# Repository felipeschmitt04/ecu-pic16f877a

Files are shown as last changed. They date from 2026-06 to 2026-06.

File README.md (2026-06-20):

# ECU with PIC16F877A

Academic embedded systems project developed for a **Microprocessors and
Microcontrollers** course in the Computer Engineering program at UFSC. The goal
was to build an educational ECU prototype that simulates basic combustion engine
control while integrating embedded firmware, sensor acquisition, actuator
control, an LCD interface, circuit simulation, and PCB design.

> **Disclaimer:** this project is intended for academic and portfolio purposes.
> It has not been validated for real automotive use and must not be used to
> control an actual engine without proper electrical, mechanical, and safety
> reviews.

## Overview

The ECU firmware was written in C for the **PIC16F877A** microcontroller using
MPLAB X and the XC8 compiler. The system reads simulated analog sensors, applies
fuel injection maps, controls injectors, ignition outputs, auxiliary actuators,
and displays runtime data on a 16x2 LCD.

The project includes:

- Proteus circuit simulation;
- KiCad schematic and PCB design;
- economy and performance injection maps;
- active map persistence using internal EEPROM;
- button-based user interface with LCD feedback;
- timer and interrupt-driven control logic.

## Visual Documentation

The repository includes exported hardware views that document the path from the
electrical design to the final PCB layout.

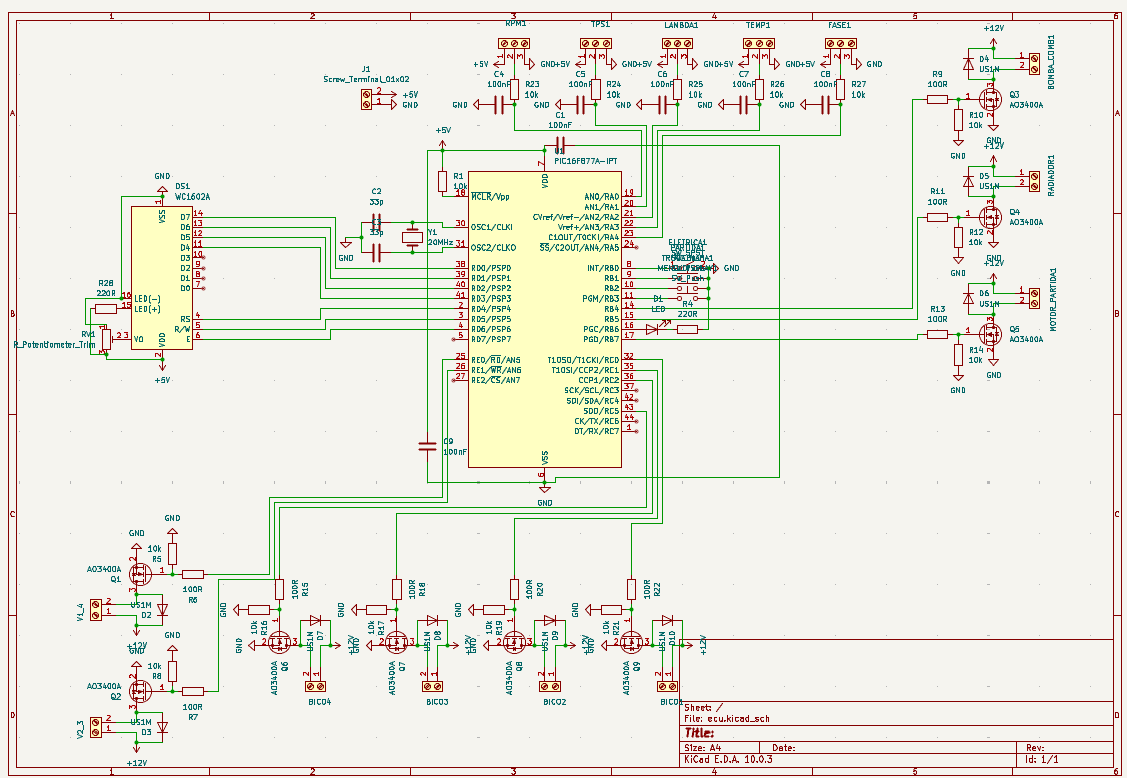
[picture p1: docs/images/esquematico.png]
KiCad schematic of the ECU circuit


The schematic centers on the PIC16F877A and shows the simulated sensor inputs,
LCD interface, user buttons, power connections, and MOSFET-based output stages
used to represent injectors, ignition pairs, the fuel pump, radiator fan,
starter motor, and warning indicators.

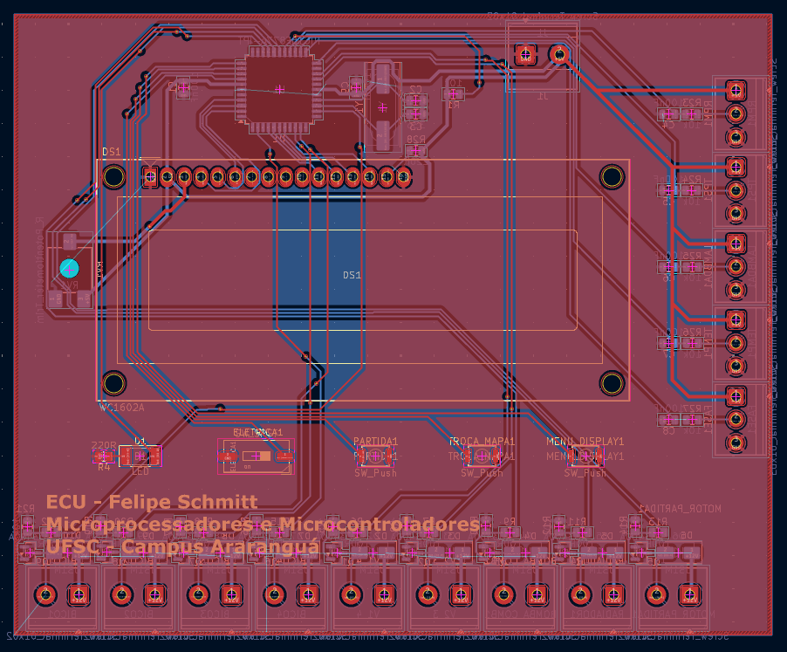
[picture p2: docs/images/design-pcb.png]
KiCad PCB routing view


The PCB layout shows the two-layer board routing, with the LCD and user controls
placed on the front side and the sensor/actuator connectors distributed around
the board edges for easier access during testing.

| Front side | Back side |
| --- | --- |
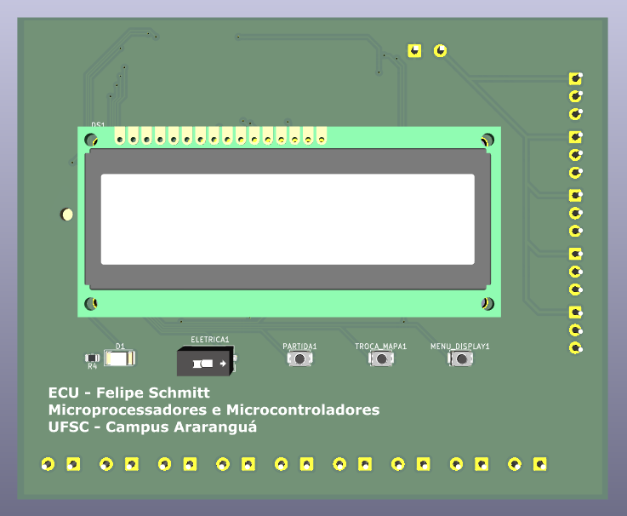
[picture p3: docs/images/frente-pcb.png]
Front render of the ECU PCB
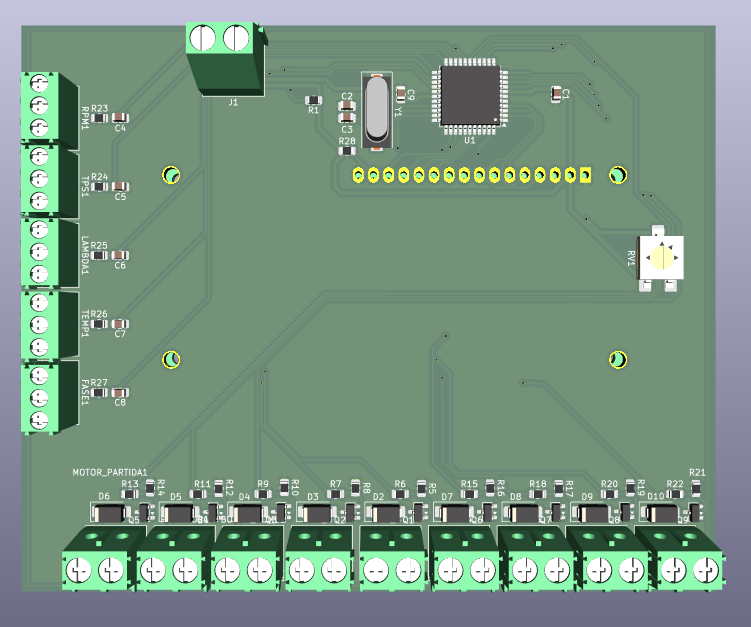
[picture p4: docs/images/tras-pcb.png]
Back render of the ECU PCB
|  |  |

The 3D renders highlight the intended physical organization of the prototype:
LCD and buttons on the user-facing side, and the microcontroller, connectors,
crystal oscillator, potentiometer, and driver stages on the opposite side.

## Features

- ADC reading for simulated sensors:
  - TPS;
  - RPM;
  - lambda/oxygen sensor;
  - temperature.
- Two injection maps:
  - economy;
  - performance.
- Sequential injector control.
- Paired ignition output control.
- Auxiliary actuator control:
  - fuel pump;
  - radiator fan;
  - starter motor;
  - check engine LED.
- Simulated open-loop and closed-loop modes.
- RPM limiter.
- Start enrichment logic.
- Multi-screen 16x2 LCD interface.

## How the ECU Works

The firmware runs a simple ECU control loop around four simulated analog
signals: throttle position, RPM, lambda/oxygen feedback, and temperature. Each
loop iteration reads the sensors through the PIC ADC, updates the engine state,
selects a fuel value from a 16x16 lookup table, applies correction rules, and
updates the auxiliary actuators and LCD.

The fuel maps use RPM and TPS as axes. The 10-bit ADC readings are compressed
to 4-bit indexes, producing 16 RPM bands and 16 throttle bands:

```c
rpm_index = adc_rpm >> 6;
tps_index = adc_tps >> 6;
map_index = rpm_index * 16 + tps_index;
```

Two maps are available: an economy map with lower base injection values and a
performance map with richer values. The selected map is stored in internal
EEPROM so the ECU can restore it after a reset.

Timer1 schedules the engine events according to the simulated RPM. On each
Timer1 interrupt, the firmware advances a four-step engine sequence, triggers
one ignition pair, and opens one injector. Timer2 then controls the injector
pulse width and turns all injectors off when the pulse ends.

For a deeper breakdown of the sensors, maps, correction logic, and actuator
states, see [ECU operation](docs/ecu-operation.md).

## Architecture

```mermaid
flowchart LR
    A["Simulated sensors<br/>TPS, RPM, lambda, temperature"] --> B["PIC16F877A ADC"]
    B --> C["ECU logic<br/>maps, corrections, limits"]
    C --> D["Timers and interrupts"]
    D --> E["Injectors"]
    D --> F["Ignition outputs"]
    C --> G["Auxiliary actuators<br/>pump, fan, starter"]
    C --> H["16x2 LCD"]
    I["Buttons"] --> C
    C --> J["Internal EEPROM<br/>active map"]
```

## Project Structure

```text
.
├── Software-MPLab/
│   └── ecu_final.X/        # C firmware for MPLAB X / XC8
├── Hardware-Proteus/       # Circuit simulation
├── PCB-Kicad/
│   └── ecu/                # Schematic and PCB files
└── docs/                   # Technical notes and portfolio assets
```

## Technologies

- **Language:** C
- **Microcontroller:** PIC16F877A
- **IDE/Compiler:** MPLAB X + XC8
- **Simulation:** Proteus
- **PCB Design:** KiCad
- **Interface:** 16x2 LCD in 4-bit mode

## How to Open

### Firmware

1. Open `Software-MPLab/ecu_final.X` in MPLAB X.
2. Confirm that the selected device is `PIC16F877A`.
3. Build the project with the XC8 compiler.

### Simulation

1. Open `Hardware-Proteus/ecu3.pdsprj` in Proteus.
2. Attach the `.hex` file generated by MPLAB to the simulated microcontroller,
   if required.
3. Run the simulation and vary the sensor inputs to observe the ECU behavior.

### PCB

1. Open `PCB-Kicad/ecu/ecu.kicad_pro` in KiCad.
2. Review the schematic and PCB layout.
3. Run ERC/DRC before considering any manufacturing step.

## Known Limitations

This project was developed as an academic prototype. Before any use beyond
simulation, the following areas would need additional work:

- validate the electrical sizing of inductive load drivers;
- replace floating-point calculations with integer or fixed-point arithmetic to
  reduce program memory usage;
- protect variables shared between `main` and interrupt routines;
- review LCD buffers and string formatting;
- make the build reproducible outside the original MPLAB/XC8 environment;
- run and document KiCad ERC/DRC results.

## Outcome

The project was presented for the Microprocessors and Microcontrollers course
and received the maximum grade. It demonstrates practical integration between
embedded firmware, analog/digital electronics, real-time control, circuit
simulation, and PCB design.

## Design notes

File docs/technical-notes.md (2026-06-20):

# Technical Notes

## Academic Goal

The goal of this project was to apply microprocessor and microcontroller
concepts in an embedded system with multiple inputs and outputs, real-time
timing requirements, and interaction with simulated hardware.

## Firmware

The firmware is centered around `Software-MPLab/ecu_final.X/main.c` and uses:

- PIC16F877A configuration bits;
- ADC for sensor acquisition;
- Timer1 as the base timing source for the engine cycle;
- Timer2 for injector pulse duration;
- interrupts for injection and ignition timing events;
- internal EEPROM to store the active map;
- a 16x2 LCD for the local interface.

## Inputs

| Input | Function |
| --- | --- |
| AN0 | Simulated TPS |
| AN1 | Simulated RPM |
| AN2 | Simulated lambda/oxygen sensor |
| AN3 | Simulated temperature |
| RB0 | Ignition switch |
| RB1 | Starter button |
| RB2 | Map switch / loop mode |
| RB3 | Display menu |

## Outputs

| Output | Function |
| --- | --- |
| RB4 | Fuel pump |
| RB5 | Radiator fan |
| RB6 | Check engine LED |
| RB7 | Starter motor |
| RC0, RC1, RC2, RC5 | Injectors |
| RE0, RE1 | Ignition pairs |
| RD0-RD4, RD6 | 16x2 LCD |

## Control Logic

RPM and TPS values select an entry from a 16x16 lookup table. The selected
value defines the base injector pulse time. The ECU also applies additional
rules for engine start, RPM limiting, deceleration fuel cut, and lambda-based
correction in simulated closed-loop mode.

A more detailed explanation of the runtime behavior is available in
[ECU operation](ecu-operation.md).

## Hardware Documentation

The `docs/images` directory contains exported views used to document the
hardware portion of the project:

- `esquematico.png`: KiCad schematic with the PIC16F877A, simulated analog
  sensors, LCD, buttons, and actuator driver stages.
- `design-pcb.png`: PCB routing view showing the two-layer board layout.
- `frente-pcb.png`: front 3D render with the LCD, user controls, and silkscreen.
- `tras-pcb.png`: back 3D render with the microcontroller, connectors, crystal,
  potentiometer, and output driver circuitry.

## Learning Outcomes

- Peripheral configuration on an 8-bit microcontroller.
- Timer and interrupt-driven event handling.
- ADC acquisition and conversion of simulated physical quantities.
- Calibration map organization.
- Integration between firmware, simulation, and PCB design.
- Practical program memory constraints in small microcontrollers.

## Future Improvements

- Split the firmware into smaller modules.
- Replace floating-point calculations with fixed-point arithmetic.
- Add abstraction layers for the LCD and actuators.
- Add logic tests for maps and limit conditions.
- Add Proteus screenshots to complement the KiCad schematic and PCB renders.
- Review ERC/DRC results and document them in the repository.

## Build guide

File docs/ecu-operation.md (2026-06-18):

# ECU Operation

This document describes how the simulated ECU firmware works at a higher level:
which sensors are read, how the fuel maps are indexed, how the engine state is
updated, and how the outputs are driven.

## Main Control Loop

The firmware starts by configuring the PIC16F877A ports, ADC, timers, LCD, and
interrupts. It then reads the last selected fuel map from internal EEPROM and
enters the main loop.

When the ignition switch is active, each loop iteration performs the following
steps:

1. Read buttons and update the user interface state.
2. Read analog sensors through the ADC.
3. Detect whether the starter button is pressed.
4. Calculate the engine logic and injector pulse value.
5. Update auxiliary actuators.
6. Refresh the LCD periodically.

When the ignition switch is off, the firmware disables the pump, fan, starter,
ignition outputs, injectors, and timers.

## Sensor Inputs

The project uses simulated sensors connected to the PIC ADC channels.

| ADC channel | Variable | Simulated signal | Firmware interpretation |
| --- | --- | --- | --- |
| AN0 | `g_adc_tps` | Throttle position sensor | Used as the TPS axis of the fuel map and for deceleration fuel cut |
| AN1 | `g_adc_rpm_sim` | RPM potentiometer/signal | Converted into simulated engine speed and used as the RPM axis |
| AN2 | `g_adc_sonda` | Lambda/oxygen sensor | Converted into an AFR-like value for closed-loop correction |
| AN3 | `g_adc_temp` | Temperature sensor | Converted into degrees Celsius for fan control and warnings |

The ADC returns a 10-bit value from 0 to 1023. The simulated RPM is calculated
as:

```c
g_rpm_real = g_adc_rpm_sim * 8;
```

This maps the ADC range to approximately 0 to 8184 RPM.

The simulated lambda input is converted into an AFR-like range from 10.0 to
20.0:

```c
afr_lido = 10.0 + (g_adc_sonda * 10.0 / 1023.0);
```

Temperature is approximated with:

```c
temperatura = g_adc_temp * 0.4887;
```

## Digital Inputs

| Pin | Symbol | Function |
| --- | --- | --- |
| RB0 | `SW_IGNICAO` | Ignition switch |
| RB1 | `SW_PARTIDA` | Starter button |
| RB2 | `SW_MAPA` | Short press changes fuel map; long press changes loop mode |
| RB3 | `SW_MENU` | Cycles LCD display screens |

The inputs use active-low logic in the firmware, so a pressed/active switch is
read as `0`.

## Engine State

The firmware tracks three main operating states:

| State variable | Meaning |
| --- | --- |
| `g_ignicao_ligada` | Ignition switch is active |
| `g_modo_partida` | Starter button is pressed |
| `g_motor_girando` | Engine is considered running |

The engine is considered running when the starter is active and the simulated
RPM is above 300 RPM. If the engine is already running and RPM drops below 400
RPM, the firmware considers the engine stopped and disables Timer1 and all
injectors.

## Fuel Maps

The project contains two 16x16 fuel maps:

- `MAPA_ECONOMICO`: lower base injection values for economy mode;
- `MAPA_PERFORMANCE`: higher base injection values for performance mode.

Both maps contain 256 entries. The axes are simulated RPM and TPS. Since each
ADC reading is 10 bits, the firmware compresses each value into a 4-bit index:

```c
rpm_index = g_adc_rpm_sim >> 6;  // 0 to 15
tps_index = g_adc_tps >> 6;      // 0 to 15
index_linear = rpm_index * 16 + tps_index;
```

The selected map entry becomes the base injector pulse value:

```c
tempo_base = MAPA_ECONOMICO[index_linear];
// or
tempo_base = MAPA_PERFORMANCE[index_linear];
```

The active map is saved in EEPROM address `0` when changed while the engine is
not running. On startup, the firmware restores the saved map; invalid values
fall back to the economy map.

## Fuel Corrections

After reading the base value from the selected map, the firmware applies several
rules.

### Closed-Loop Correction

When closed-loop mode is enabled, the simulated lambda sensor is converted into
an AFR-like value. The target AFR is fixed at 14.7. A correction factor is
computed and clamped between 0.70 and 1.30 to avoid extreme corrections.

### RPM Limiter

If simulated RPM exceeds `RPM_LIMITE` (`6500`), the firmware sets the final
injection value to zero.

### Deceleration Fuel Cut

If TPS is near zero and RPM is above 1800, the firmware also sets the final
injection value to zero to simulate fuel cut during deceleration.

### Start Enrichment

When the starter is active, the final injection value is multiplied by 1.3 to
simulate a richer mixture during start.

### Timer2 Limit

The final value is capped at 255 because it is stored in an 8-bit Timer2 period
register value.

## Timer-Based Injection and Ignition

The firmware uses two timers:

| Timer | Purpose |
| --- | --- |
| Timer1 | Schedules engine events according to simulated RPM |
| Timer2 | Ends the injector pulse |

Timer1 is reloaded with a value calculated from the simulated RPM:

```c
ticks = 18750000 / g_rpm_real;
g_timer1_preload = 65535 - ticks;
```

On each Timer1 interrupt, the firmware advances a four-step sequence:

| Step | Ignition output | Injector opened |
| --- | --- | --- |
| 0 | `VELA_1_4` | `BICO_3` |
| 1 | `VELA_2_3` | `BICO_4` |
| 2 | `VELA_1_4` | `BICO_2` |
| 3 | `VELA_2_3` | `BICO_1` |

After opening an injector, Timer2 is started with the calculated pulse value.
When Timer2 overflows, all injectors are turned off.

## Auxiliary Actuators

| Output | Pin | Behavior |
| --- | --- | --- |
| Fuel pump | RB4 | Turns on while the engine is running; also primes briefly after ignition is switched on |
| Radiator fan | RB5 | Turns on above 95 C and turns off below 90 C |
| Check engine LED | RB6 | Turns on for TPS fault, high temperature, or RPM limiter condition |
| Starter motor | RB7 | Turns on while starter mode is active and the engine is not yet running |

The system shutdown routine clears all auxiliary outputs, ignition outputs,
injectors, and timers.

## LCD Interface

The LCD has three display modes:

| Mode | Displayed information |
| --- | --- |
| General | RPM, TPS, AFR, or a sport-style RPM bar depending on the active map |
| Map | Active fuel map and loop mode |
| Warnings | Temperature and system warnings |

The menu button cycles between these modes. The map button changes the fuel map
on a short press and toggles open-loop/closed-loop mode on a long press.

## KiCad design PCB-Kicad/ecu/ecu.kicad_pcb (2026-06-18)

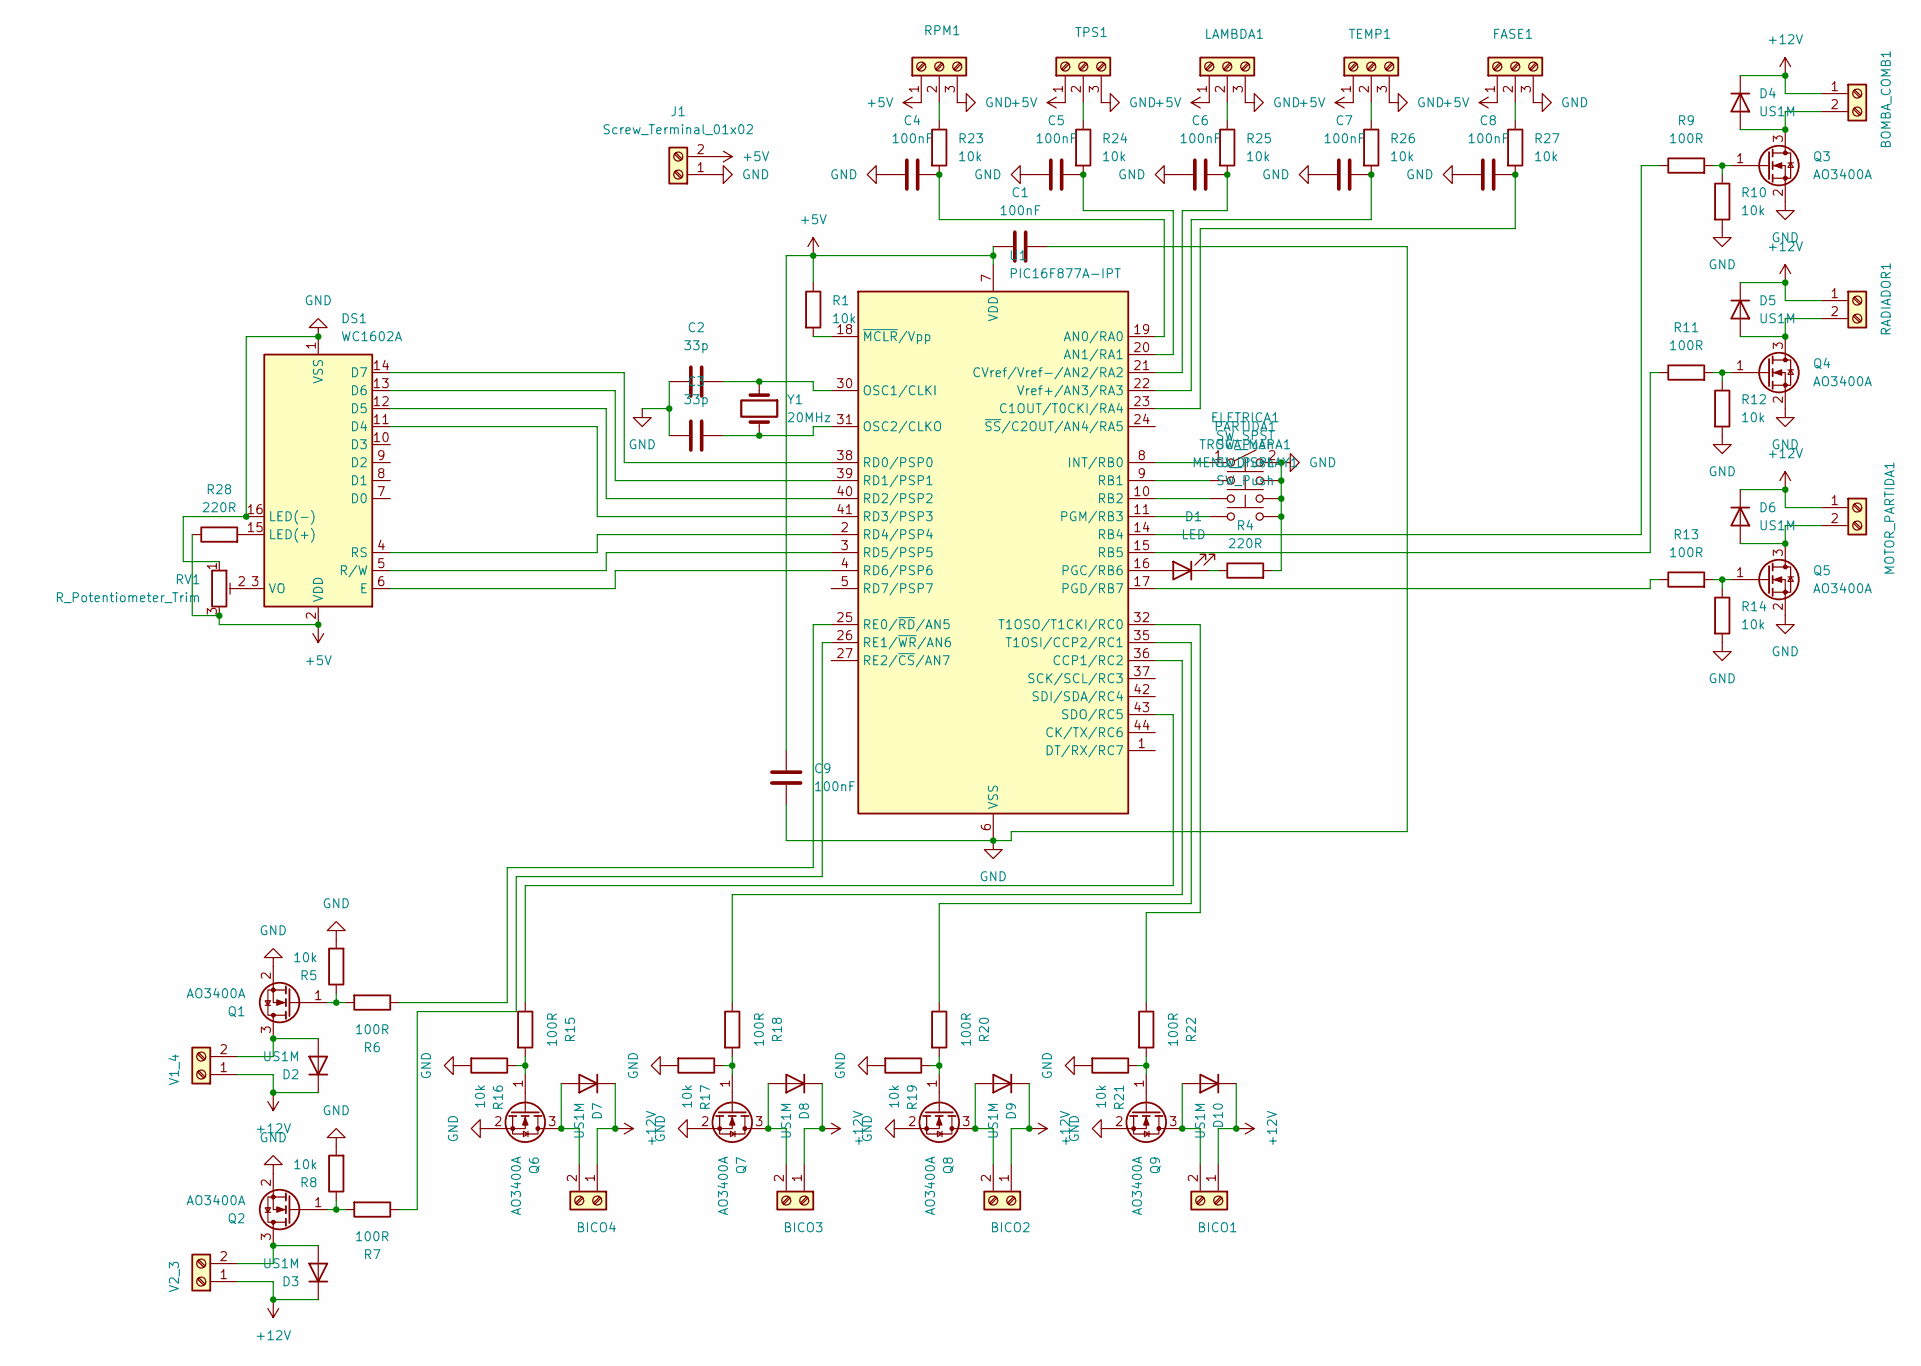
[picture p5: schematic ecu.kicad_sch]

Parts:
BICO1, BICO2, BICO3, BICO4: Screw_Terminal_01x02; TerminalBlock_Phoenix_PT-1,5-2-5.0-H_1x02_P5.00mm_Horizontal
BOMBA_COMB1: Screw_Terminal_01x02; TerminalBlock_Phoenix_PT-1,5-2-5.0-H_1x02_P5.00mm_Horizontal
C1, C4, C5, C6, C7, C8, C9: 100nF; C_0805_2012Metric
C2, C3: 33p; C_0805_2012Metric
D1: LED; LED_2010_5025Metric
D2, D3, D4, D5, D6, D7, D8, D9, D10: US1M; D_SMA
DS1: WC1602A
ELETRICA1: SW_SPST; SW_DIP_SPSTx01_Slide_9.78x4.72mm_W8.61mm_P2.54mm
FASE1: Screw_Terminal_01x03; TerminalBlock_Phoenix_PT-1,5-3-3.5-H_1x03_P3.50mm_Horizontal
J1: Screw_Terminal_01x02; TerminalBlock_Phoenix_MKDS-1,5-2-5.08_1x02_P5.08mm_Horizont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
LAMBDA1: Screw_Terminal_01x03; TerminalBlock_Phoenix_PT-1,5-3-3.5-H_1x03_P3.50mm_Horizontal
MENU_DISPLAY1: SW_Push; SW_Push_SPST_NO_Alps_SKRK
MOTOR_PARTIDA1: Screw_Terminal_01x02; TerminalBlock_Phoenix_PT-1,5-2-5.0-H_1x02_P5.00mm_Horizontal
PARTIDA1: SW_Push; SW_Push_SPST_NO_Alps_SKRK
Q1, Q2, Q3, Q4, Q5, Q6, Q7, Q8, Q9: AO3400A; SOT-23
R1, R5, R8, R10, R12, R14, R16, R17, R19, R21, R23, R24, R25, R26, R27: 10k; R_0805_2012Metric
R4, R28: 220R; R_0805_2012Metric
R6, R7, R9, R11, R13, R15, R18, R20, R22: 100R; R_0805_2012Metric
RADIADOR1: Screw_Terminal_01x02; TerminalBlock_Phoenix_PT-1,5-2-5.0-H_1x02_P5.00mm_Horizontal
RPM1: Screw_Terminal_01x03; TerminalBlock_Phoenix_PT-1,5-3-3.5-H_1x03_P3.50mm_Horizontal
RV1: R_Potentiometer_Trim; Potentiometer_ACP_CA6-VSMD_Vertical_Hole
TEMP1: Screw_Terminal_01x03; TerminalBlock_Phoenix_PT-1,5-3-3.5-H_1x03_P3.50mm_Horizontal
TPS1: Screw_Terminal_01x03; TerminalBlock_Phoenix_PT-1,5-3-3.5-H_1x03_P3.50mm_Horizontal
TROCA_MAPA1: SW_Push; SW_Push_SPST_NO_Alps_SKRK
U1: PIC16F877A-IPT; TQFP-44_10x10mm_P0.8mm
V1_4, V2_3: Screw_Terminal_01x02; TerminalBlock_Phoenix_PT-1,5-2-5.0-H_1x02_P5.00mm_Horizontal
Y1: 20MHz; Crystal_SMD_HC49-SD

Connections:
+5V: C1.1, C9.2, DS1.2 (VDD), FASE1.1, J1.2, LAMBDA1.1, R1.1, R28.1, RPM1.1, RV1.3, TEMP1.1, TPS1.1, U1.7 (VDD), U1.28 (VDD)
+12V: BICO1.1, BICO2.1, BICO3.1, BICO4.1, BOMBA_COMB1.1, D2.1 (K), D3.1 (K), D4.1 (K), D5.1 (K), D6.1 (K), D7.1 (K), D8.1 (K), D9.1 (K), D10.1 (K), MOTOR_PARTIDA1.1, RADIADOR1.1, V1_4.1, V2_3.1
GND: C1.2, C2.1, C3.1, C4.1, C5.1, C6.1, C7.1, C8.1, C9.1, DS1.1 (VSS), DS1.16 (LED(-)), ELETRICA1.2 (B), FASE1.3, J1.1, LAMBDA1.3, MENU_DISPLAY1.2, PARTIDA1.2, Q1.2 (S), Q2.2 (S), Q3.2 (S), Q4.2 (S), Q5.2 (S), Q6.2 (S), Q7.2 (S), Q8.2 (S), Q9.2 (S), R4.2, R5.2, R8.2, R10.2, R12.2, R14.2, R16.2, R17.2, R19.2, R21.2, RPM1.3, RV1.1, TEMP1.3, TPS1.3, TROCA_MAPA1.2, U1.6 (VSS), U1.29 (VSS)
unnamed: BICO1.2, D10.2 (A), Q9.3 (D)
unnamed: BICO2.2, D9.2 (A), Q8.3 (D)
unnamed: BICO3.2, D8.2 (A), Q7.3 (D)
unnamed: BICO4.2, D7.2 (A), Q6.3 (D)
unnamed: BOMBA_COMB1.2, D4.2 (A), Q3.3 (D)
unnamed: D1.2 (A), U1.16 (PGC/RB6)
unnamed: D1.1 (K), R4.1
unnamed: D2.2 (A), Q1.3 (D), V1_4.2
unnamed: D3.2 (A), Q2.3 (D), V2_3.2
unnamed: D5.2 (A), Q4.3 (D), RADIADOR1.2
unnamed: D6.2 (A), MOTOR_PARTIDA1.2, Q5.3 (D)
unnamed: DS1.11 (D4), U1.41 (RD3/PSP3)
unnamed: DS1.12 (D5), U1.40 (RD2/PSP2)
unnamed: DS1.13 (D6), U1.39 (RD1/PSP1)
unnamed: DS1.14 (D7), U1.38 (RD0/PSP0)
unnamed: DS1.6 (E), U1.4 (RD6/PSP6)
unnamed: DS1.15 (LED(+)), R28.2
unnamed: DS1.4 (RS), U1.2 (RD4/PSP4)
unnamed: DS1.5 (R/W), U1.3 (RD5/PSP5)
unnamed: DS1.3 (VO), RV1.2
unnamed: ELETRICA1.1 (A), U1.8 (INT/RB0)
unnamed: FASE1.2, R27.1
unnamed: LAMBDA1.2, R25.1
unnamed: Q1.1 (G), R5.1, R6.2
unnamed: Q2.1 (G), R7.2, R8.1
unnamed: Q3.1 (G), R9.2, R10.1
unnamed: Q4.1 (G), R11.2, R12.1
unnamed: Q5.1 (G), R13.2, R14.1
unnamed: Q6.1 (G), R15.2, R16.1
unnamed: Q7.1 (G), R17.1, R18.2
unnamed: Q8.1 (G), R19.1, R20.2
unnamed: Q9.1 (G), R21.1, R22.2
unnamed: R23.1, RPM1.2
unnamed: R26.1, TEMP1.2
unnamed: R24.1, TPS1.2
unnamed: C4.2, R23.2, U1.19 (AN0/RA0)
unnamed: C5.2, R24.2, U1.20 (AN1/RA1)
unnamed: C8.2, R27.2, U1.23 (C1OUT/T0CKI/RA4)
unnamed: R18.1, U1.36 (CCP1/RC2)
unnamed: C6.2, R25.2, U1.21 (CVref/Vref-/AN2/RA2)
unnamed: C2.2, U1.30 (OSC1/CLKI), Y1.1
unnamed: C3.2, U1.31 (OSC2/CLKO), Y1.2
unnamed: R13.1, U1.17 (PGD/RB7)
unnamed: MENU_DISPLAY1.1, U1.11 (PGM/RB3)
unnamed: PARTIDA1.1, U1.9 (RB1)
unnamed: TROCA_MAPA1.1, U1.10 (RB2)
unnamed: R9.1, U1.14 (RB4)
unnamed: R11.1, U1.15 (RB5)
unnamed: R6.1, U1.25 (RE0/~RD/AN5)
unnamed: R7.1, U1.26 (RE1/~WR/AN6)
unnamed: R15.1, U1.43 (SDO/RC5)
unnamed: R20.1, U1.35 (T1OSI/CCP2/RC1)
unnamed: R22.1, U1.32 (T1OSO/T1CKI/RC0)
unnamed: C7.2, R26.2, U1.22 (Vref+/AN3/RA3)
unnamed: R1.2, U1.18 (~MCLR/Vpp)

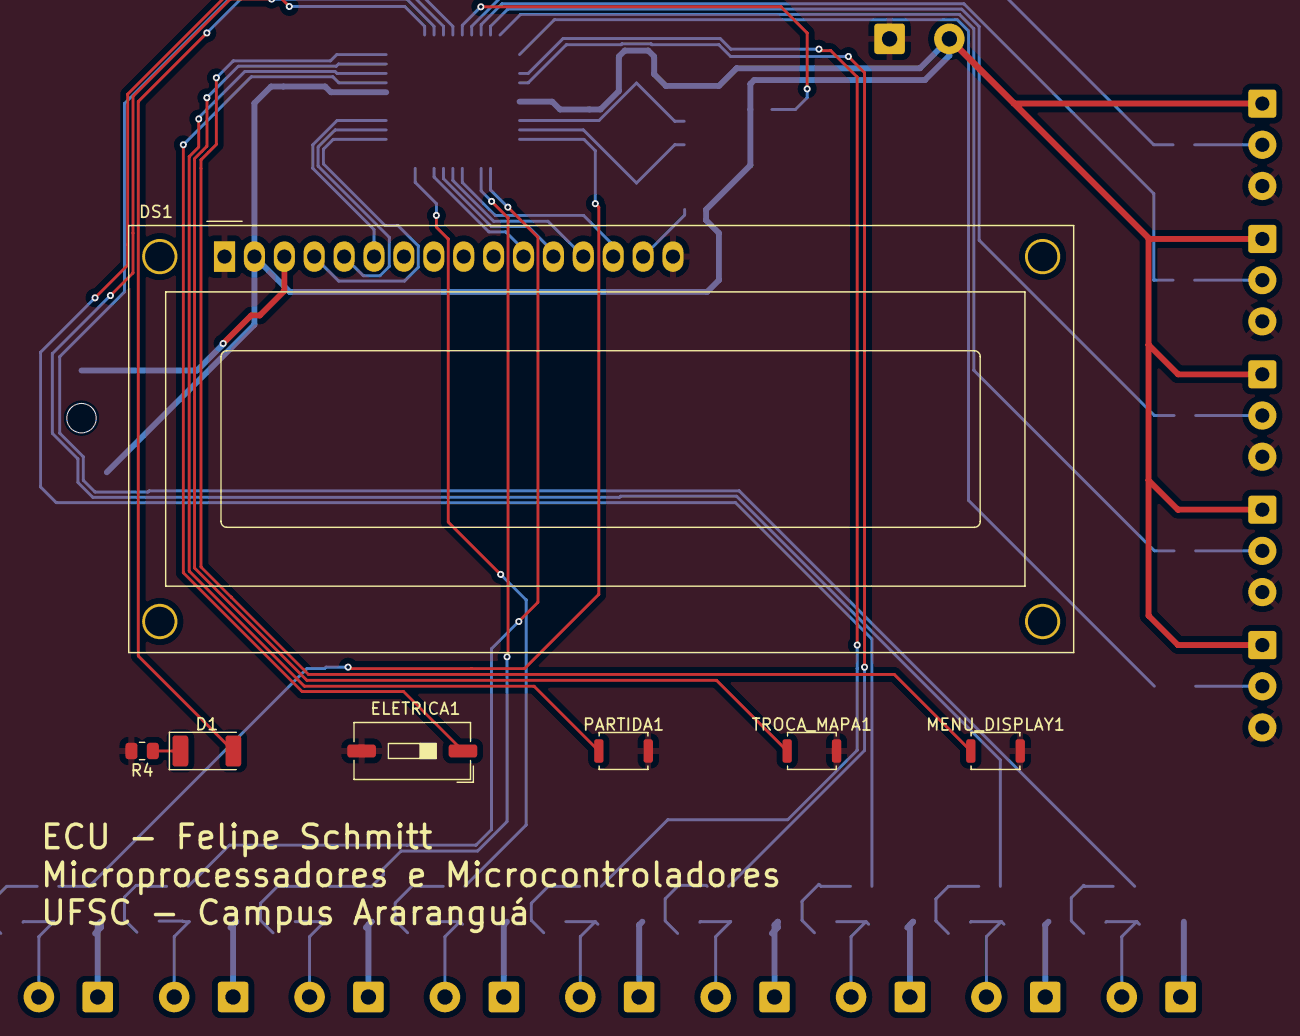
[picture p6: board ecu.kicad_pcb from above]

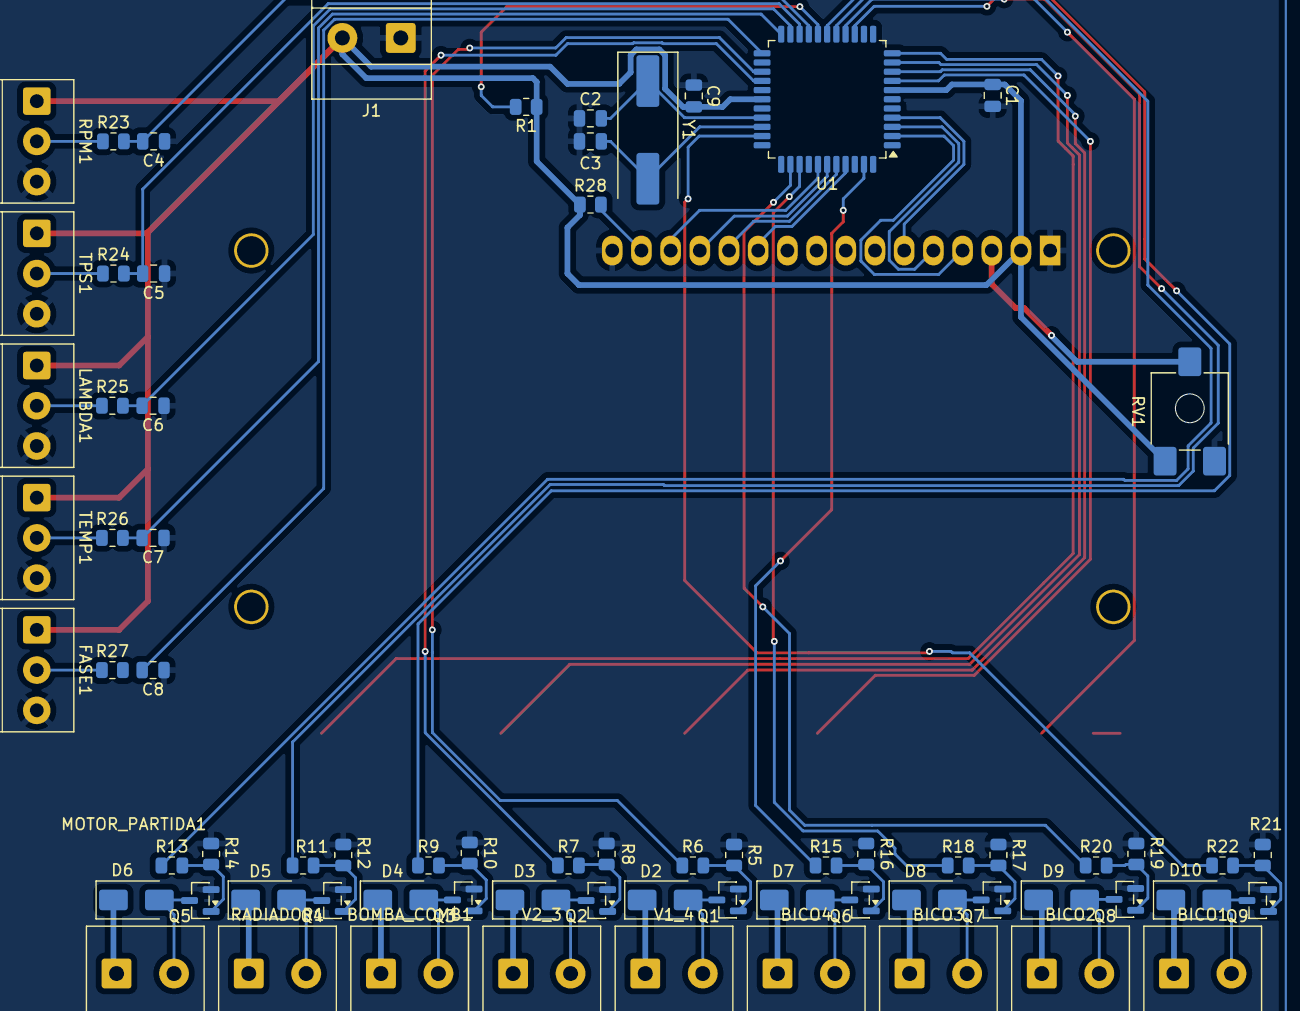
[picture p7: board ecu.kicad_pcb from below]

Board: 2 copper layers, 77 parts (70 on the bottom side), 58 nets.

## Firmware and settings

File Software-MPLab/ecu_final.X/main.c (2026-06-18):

/*
 * File:   main.c
 * Author: Felipe Luan Schmitt
 * Project: ECU
 * Subject: Microprocessadores e Microcontroladores
 * Course: Engenharia da Computacao
 * University: UFSC Campus Ararangua
 */

/*
 * BITS DE CONFIGURACAO
 */
#pragma config FOSC = HS        // Oscilador High-Speed (HS)
#pragma config WDTE = ON      // Watchdog Timer ON
#pragma config PWRTE = ON       // Power-up Timer ON
#pragma config BOREN = ON       // Brown-out Reset ON
#pragma config LVP = OFF        // Low-Voltage Programming OFF
#pragma config CPD = OFF        // Data EEPROM Code Protection OFF
#pragma config WRT = OFF        // Flash Program Memory Write Enable OFF
#pragma config CP = OFF         // Flash Program Memory Code Protection OFF

/*
 * INCLUDES
 */
#include <xc.h>
#include <pic16f877a.h>
#include <stdio.h>
#include <stdlib.h>
#include <stdint.h>
#include <string.h>

#define _XTAL_FREQ 20000000 //Frequencia do crystal a 20MHz

#include "lcd.h"

#define MAP_SIZE 256 

// --- MAPA 1: ECONÔMICO ---
const uint8_t MAPA_ECONOMICO[MAP_SIZE] = {
    20, 22, 24, 26, 28, 30, 32, 34, 36, 38, 40, 42, 44, 46, 48, 50,
    22, 24, 26, 28, 30, 32, 34, 36, 38, 40, 42, 44, 46, 48, 50, 52,
    24, 26, 28, 30, 32, 34, 36, 38, 40, 42, 44, 46, 48, 50, 52, 55,
    26, 28, 30, 32, 34, 36, 38, 40, 42, 44, 46, 48, 50, 52, 55, 58,
    28, 30, 32, 34, 36, 38, 40, 42, 44, 46, 48, 50, 52, 55, 58, 61,
    30, 32, 34, 36, 38, 40, 42, 44, 46, 48, 50, 52, 55, 58, 61, 65,
    32, 34, 36, 38, 40, 42, 44, 46, 48, 50, 52, 55, 58, 61, 65, 70,
    34, 36, 38, 40, 42, 44, 46, 48, 50, 52, 55, 58, 61, 65, 70, 75,
    36, 38, 40, 42, 44, 46, 48, 50, 52, 55, 58, 61, 65, 70, 75, 80,
    38, 40, 42, 44, 46, 48, 50, 52, 55, 58, 61, 65, 70, 75, 80, 85,
    40, 42, 44, 46, 48, 50, 52, 55, 58, 61, 65, 70, 75, 80, 85, 90,
    42, 44, 46, 48, 50, 52, 55, 58, 61, 65, 70, 75, 80, 85, 90, 95,
    44, 46, 48, 50, 52, 55, 58, 61, 65, 70, 75, 80, 85, 90, 95, 100,
    46, 48, 50, 52, 55, 58, 61, 65, 70, 75, 80, 85, 90, 95, 100, 105,
    48, 50, 52, 55, 58, 61, 65, 70, 75, 80, 85, 90, 95, 100, 105, 110,
    50, 52, 55, 58, 61, 65, 70, 75, 80, 85, 90, 95, 100, 105, 110, 120
};

// --- MAPA 2: PERFORMANCE ---
const uint8_t MAPA_PERFORMANCE[MAP_SIZE] = {
    25, 28, 31, 34, 37, 40, 43, 46, 50, 55, 60, 65, 70, 75, 80, 85,
    28, 31, 34, 37, 40, 43, 46, 50, 55, 60, 65, 70, 75, 80, 85, 90,
    31, 34, 37, 40, 43, 46, 50, 55, 60, 65, 70, 75, 80, 85, 90, 95,
    34, 37, 40, 43, 46, 50, 55, 60, 65, 70, 75, 80, 85, 90, 95, 105,
    37, 40, 43, 46, 50, 55, 60, 65, 70, 75, 80, 85, 90, 95, 105, 115,
    40, 43, 46, 50, 55, 60, 65, 70, 75, 80, 85, 90, 95, 105, 115, 125,
    43, 46, 50, 55, 60, 65, 70, 75, 80, 85, 90, 95, 105, 115, 125, 135,
    46, 50, 55, 60, 65, 70, 75, 80, 85, 90, 95, 105, 115, 125, 135, 145,
    50, 55, 60, 65, 70, 75, 80, 85, 90, 95, 105, 115, 125, 135, 145, 155,
    55, 60, 65, 70, 75, 80, 85, 90, 95, 105, 115, 125, 135, 145, 155, 165,
    60, 65, 70, 75, 80, 85, 90, 95, 105, 115, 125, 135, 145, 155, 165, 175,
    65, 70, 75, 80, 85, 90, 95, 105, 115, 125, 135, 145, 155, 165, 175, 185,
    70, 75, 80, 85, 90, 95, 105, 115, 125, 135, 145, 155, 165, 175, 185, 195,
    75, 80, 85, 90, 95, 105, 115, 125, 135, 145, 155, 165, 175, 185, 195, 205,
    80, 85, 90, 95, 105, 115, 125, 135, 145, 155, 165, 175, 185, 195, 205, 215,
    85, 90, 95, 105, 115, 125, 135, 145, 155, 165, 175, 185, 195, 205, 215, 225
};

/*
 * PINOS DA LCD.H
 */
#define D4 PORTDbits.RD0
#define D5 PORTDbits.RD1
#define D6 PORTDbits.RD2
#define D7 PORTDbits.RD3
#define RS PORTDbits.RD4
#define EN PORTDbits.RD6

/*
 * PINOS DO PIC
 */
//PORTA
#define FASE PORTAbits.RA4

//PORTB (entradas)
#define SW_IGNICAO PORTBbits.RB0
#define SW_PARTIDA PORTBbits.RB1
#define SW_MAPA PORTBbits.RB2
#define SW_MENU PORTBbits.RB3

//PORTB (saidas)
#define BOMBA_COMB PORTBbits.RB4
#define RADIADOR PORTBbits.RB5
#define LED_CHECK PORTBbits.RB6
#define MOTOR_PARTIDA PORTBbits.RB7

//PORTC
#define BICO_1 PORTCbits.RC0
#define BICO_2 PORTCbits.RC1
#define BICO_3 PORTCbits.RC2
#define BICO_4 PORTCbits.RC5

//PORTE
#define VELA_1_4 PORTEbits.RE0
#define VELA_2_3 PORTEbits.RE1

// RPM MAX
#define RPM_LIMITE 6500

/*
 * PROTOTIPO DE FUNCOES
 */
void setup_hardware(void);
void setup_adc(void);
void setup_timers(void);
void ler_botoes(void);
void ler_sensores(void);
void calcular_logica_motor(void);
void gerenciar_atuadores_aux(void);
void atualizar_display_lcd(void);
void desligar_sistema(void);
uint16_t read_adc(uint8_t channel);
void carregar_mapa_para_cache(uint8_t mapa_id);
void internal_eeprom_write(uint8_t addr, uint8_t data);
uint8_t internal_eeprom_read(uint8_t addr);
void itoa(uint16_t valor, char* buffer);

/*
 * VARIAVEIS GLOBAIS
 */
// flags de estado
volatile uint8_t g_ignicao_ligada = 0; //0 = desligado, controlado pelo RB0
volatile uint8_t g_motor_girando = 0; //1 = RPM > 500
volatile uint8_t g_modo_partida = 0; // 1 = botao de partida pressionado

// variaveis do motor
volatile uint16_t g_timer1_preload = 0; // valor de recarga do timer1
volatile uint8_t g_tempo_injecao_pr2 = 0; // valor de regarga do timer2

// maquina de estados do motor
static uint8_t s_engine_step = 0; // 0-3, representa o ciclo de 4 tempos do motor

// leitura de sensores
volatile uint16_t g_adc_tps = 0;
volatile uint16_t g_adc_rpm_sim = 0;
volatile uint16_t g_adc_temp = 0;
volatile uint16_t g_adc_sonda = 0;
volatile uint16_t g_rpm_real = 0;

// estados da interface
volatile uint8_t g_modo_display = 0;
volatile uint8_t g_mapa_ativo = 1; // 1 = ECO, 2 = PERF
volatile uint8_t g_modo_malha = 0; // 0 = ABERTA (Padrão), 1 = FECHADA

// timers de debounce
static uint8_t s_btn_menu_debounce = 0;
static uint8_t s_btn_mapa_debounce = 0;
static uint16_t s_btn_mapa_hold_timer = 0;

// estados do display
#define MODO_GERAL  0
#define MODO_MAPA   1
#define MODO_AVISOS 2

/*
 * ROTINA DE INTERRUPCAO
 */
/*
 * Função que gerencia os eventos em tempo real do motor. Possui a prioridade mais alta do sistema embarcado
 * e interrompe qualquer outra operação para garantir o funcionamento correto da injeção e ignição.
 * O Timer1 se baseia no RPM para acionar a ignição nas bobinas em pares (1-4 e 2-3) e iniciar a injeção no 
 * bico do pistão seguinte da ordem de combustão (1-3-4-2).
 * A interrupção do Timer2 ocorre quando o tempo de abertura do bico de injeção termina, assim, cortando
 * a alimentação dos injetores. Ele define a largura de pulso calculada com base na lógica do mapa de injeção
 */
void __interrupt() ISR(void)
{
    CLRWDT(); //limpar o WDT
    
    // interrupcao timer1 (relogio do motor)
    if(PIR1bits.TMR1IF){
        // recarrega o timer1 para a proxima interrupcao
        TMR1H = (g_timer1_preload >> 8);
        TMR1L = (g_timer1_preload & 0xFF);
        
        // condicao se a ignicao e motor estao ligados
        if(g_ignicao_ligada && g_motor_girando){
            // configura o timer2 para desligar o bico
            PR2 = g_tempo_injecao_pr2; // carrega o tempo de pulso
            T2CONbits.TMR2ON = 1; // liga o timer2
            
            // maquina de estados do motor
            switch(s_engine_step){
                case 0:
                    VELA_1_4 = 1; // pulsa nas velas 1 e 4
                    BICO_3 = 1; // abre o bico1
                    VELA_1_4 = 0;
                    break;
                
                case 1:
                    VELA_2_3 = 1;
                    BICO_4 = 1;
                    VELA_2_3 = 0;
                    break;
                    
                case 2:
                    VELA_1_4 = 1;
                    BICO_2 = 1;
                    VELA_1_4 = 0;
                    break;
                    
                case 3:
                    VELA_2_3 = 1;
                    BICO_1 = 1;
                    VELA_2_3 = 0;
                    break;
            }
            s_engine_step++;
            if (s_engine_step > 3) {
                s_engine_step = 0; // reseta o ciclo
            }
        }
        PIR1bits.TMR1IF = 0; // limpa flag do timer1
    }
    
    // interrupcao timer2 (fim do pulso de injecao)
    if(PIR1bits.TMR2IF){
        // desliga o timer2
        T2CONbits.TMR2ON = 0;
        
        // desliga todos os bicos
        BICO_1 = 0;
        BICO_2 = 0;
        BICO_3 = 0;
        BICO_4 = 0;
        
        PIR1bits.TMR2IF = 0; // limpa a flag
    }
}

/*
 * LOOP MAIN
 */
/*
 * Função principal da ECU, incializa o hardware, recupera funções salvas da EEPROM interna e gerencia
 * o ciclo de funcionamento. Opera em dois estados principais, ativo e em stand-by (quando o carro está desligado).
 * O WDT é limpo a cada ciclo.
 */
void main(void) {
    setup_hardware(); //configura TRIS,ADCON1, OPTION_REG
    
    Lcd_Init(); //inicializa o display
    Lcd_Clear(); //limpa a tela
    
    Lcd_Set_Cursor(1,1);
    Lcd_Write_String("ECU INICIADA"); //texto de inicializacao
    __delay_ms(1000);
    
    setup_adc(); // configura o conversor AD
    setup_timers(); // configura o timer1 (RPM) e timer2 (Pulso)
    
    INTCONbits.GIE = 1; // interrupcoes globais
    INTCONbits.PEIE = 1; //interrupcoes de perifericosc
    // INTCONbits.INTE = 1; // interrupcao externa (RB0)
    
    // persistencia de dados da eeprom interna para buscar o ultimo
    // estado ativo do mapa de injeção
    g_mapa_ativo = internal_eeprom_read(0);
    if(g_mapa_ativo != 1 && g_mapa_ativo != 2) {
    g_mapa_ativo = 1;
}
    
    Lcd_Clear();
    
    Lcd_Set_Cursor(1, 1);
    Lcd_Write_String("ECU DESLIGADA");
    g_ignicao_ligada = 0; // Garante que comece desligada

    while(1)
    {
        CLRWDT(); // limpa o WDT
        
        if (SW_IGNICAO == 0) 
        {
            if (g_ignicao_ligada == 0) { 
                g_ignicao_ligada = 1;
                Lcd_Clear(); 
            }

            ler_botoes(); // leitura dos botoes da interface
            ler_sensores(); // leitura dos sensores analogicos
            
            if (SW_PARTIDA == 0) g_modo_partida = 1;
            else g_modo_partida = 0;
            
            calcular_logica_motor(); // calcula o tempo de injeção com base nos mapas
            gerenciar_atuadores_aux(); // gerencia os atuadores 
            atualizar_display_lcd(); // atualiza o display
            __delay_ms(1);
        }
        else 
        {
            if (g_ignicao_ligada == 1) {
                g_ignicao_ligada = 0;
                desligar_sistema(); // garante que os atuadores fiquem desligados
            }
        }
    }
    return;
}

/*
 * FUNCOES DE LEITURA (ADC E BOTOES) 
 */
uint16_t read_adc(uint8_t channel){
    ADCON0bits.CHS = channel; //seleciona o canal (0-4)
    __delay_us(20);
    ADCON0bits.GO_nDONE = 1; // inicia a conversao
    while(ADCON0bits.GO_nDONE); // espera a conversao acabar
    return ((ADRESH << 8) | ADRESL); // retorna o resultado de 10 bits
}

void ler_sensores(void){
    g_adc_tps = read_adc(0); // AN0 = TPS
    g_adc_rpm_sim = read_adc(1); // AN1 = RPM simulado
    g_adc_sonda = read_adc(2); // AN2 = sonda lambda simulada
    g_adc_temp = read_adc(3); // AN3 = g_adc_temp
}

// --- FUNCAO DE LEITURA DOS BOTOES ---
void ler_botoes(void){
    // logica do botao MENU
    if (SW_MENU == 0 && s_btn_menu_debounce == 0) {
        s_btn_menu_debounce = 1; 
        g_modo_display++;
        
        if (g_modo_display > MODO_AVISOS) { 
            g_modo_display = MODO_GERAL; 
        }
    } else if (SW_MENU == 1) {
        s_btn_menu_debounce = 0;
    }
    // logica do botao menu, quando apertado troca entre mapas
    // quando segurado alterna entre malha aberta e fechada
    if (SW_MAPA == 0) { 
        if (s_btn_mapa_debounce == 0) {
            s_btn_mapa_debounce = 1; 
            s_btn_mapa_hold_timer = 0; 
        }
        
        if (s_btn_mapa_debounce == 1) {
            s_btn_mapa_hold_timer++;

            if (s_btn_mapa_hold_timer > 400) { 
                g_modo_malha = !g_modo_malha; 
                
                Lcd_Clear();
                Lcd_Set_Cursor(1,1);
                if(g_modo_malha) Lcd_Write_String("MALHA FECHADA");
                else Lcd_Write_String("MALHA ABERTA");
                __delay_ms(500); 
                Lcd_Clear();
                
                s_btn_mapa_debounce = 2; 
            }
        }
    } else { 
        if (s_btn_mapa_debounce == 1) { 
            if (g_mapa_ativo == 1) {
                g_mapa_ativo = 2;
            } else {
                g_mapa_ativo = 1;
            }
            if(g_motor_girando == 0){
                internal_eeprom_write(0, g_mapa_ativo);
            }
            
            Lcd_Clear(); 
        }
        
        s_btn_mapa_debounce = 0; 
        s_btn_mapa_hold_timer = 0;
    }
}

// --- CÁLCULOS DE MAPA E TIMERS ---
/*
 * Funcao que realiza os calculos matematicos e fisicos para determinar
 * o tempo de ignição e a quantidade de combustivel (tempo de injecao) com
 * base no mapa.
 * Faz interpolacao do TPS x RPM para buscar o tempo base.
 * Realiza correcao em tempo real com base na sonda lambda
 * Rev limiter para manter o giro maximo em 6500
 * Enriquecimento de mistura para partida com motor frio
 * Corte de combustível em desaceleracao
 */
void calcular_logica_motor(void) {
    g_rpm_real = (uint16_t)(g_adc_rpm_sim * 8); // converte a leitura adc para uma escada realista (0-1023 para 0-8184 RPM)

    // maquina de estados do motor
    if (g_motor_girando == 0) {
        if (g_modo_partida == 1 && g_rpm_real > 300) {
            g_motor_girando = 1;
        } else {
            g_motor_girando = 0;
            T1CONbits.TMR1ON = 0;
            s_engine_step = 0;
            BICO_1 = 0; BICO_2 = 0; BICO_3 = 0; BICO_4 = 0;
            return;
        }
    } else {
        // se a rotacao cair de 400 RPM o motor "morre"
        if (g_rpm_real < 400) {
            g_motor_girando = 0;
        }
    }

    // busca o RPM e o TPS e converte de 10 bits para 4 usando bitwise shift
    uint8_t rpm_index = g_adc_rpm_sim >> 6;
    uint8_t tps_index = g_adc_tps >> 6;
    uint16_t index_linear = (rpm_index * 16) + tps_index; // converte a matriz 2D para 1D
    
    uint8_t tempo_base;

    // seleciona o mapa
    if (g_mapa_ativo == 1) {
        tempo_base = MAPA_ECONOMICO[index_linear];
    } else {
        tempo_base = MAPA_PERFORMANCE[index_linear];
    }
    
    float tempo_final_float = (float)tempo_base;
    
    if (g_modo_malha == 1) {
        float afr_alvo = 14.7; // Alvo Fixo
        
        float afr_lido = 10.0 + ((float)g_adc_sonda * 10.0 / 1023.0); // conversao do ADC para o AFR (de 10 a 20)
        
        if (afr_lido > 9.0) {
            float correcao = afr_alvo / afr_lido; // calculo da correcao
            
            // limitador de correcao para impedir correcoes absurdas
            if (correcao > 1.30) correcao = 1.30; 
            if (correcao < 0.70) correcao = 0.70; 
            
            tempo_final_float = tempo_final_float / correcao;
        }
    }
    
    if (g_rpm_real > RPM_LIMITE) {
        tempo_final_float = 0; // corta injeção (tempo zero)
    }
    
    uint8_t tps_minimo = (g_adc_tps < 20); // considerando margem do sensor
    uint8_t rpm_cutoff = (g_rpm_real > 1800);
    
    if (tps_minimo && rpm_cutoff) {
        tempo_final_float = 0; // corta combustível para economizar
    }
    
    // enriquecimento de partida
    if (g_modo_partida) {
        tempo_final_float = tempo_final_float * 1.3;
    }
    
    // protecao contra overflow do timer2
    if (tempo_final_float > 255.0) tempo_final_float = 255.0;
    
    // calculo do timer1
    if (g_rpm_real > 0) {
        uint32_t ticks = 18750000 / g_rpm_real;
        g_timer1_preload = 65535 - (uint16_t)ticks;
    }
    
    g_tempo_injecao_pr2 = (uint8_t)tempo_final_float;
    T1CONbits.TMR1ON = 1;
}

/*
 * Funcao que controla os atuadores que nao dependem diretamente do giro do motor.
 * Controla a bomba de combustivel.
 * Acionar ventoinha do radiador quando a temperatura esta elevada.
 * Responsavel pelo motor de partida.
 * Diagnostico de alertas de falha.
 */
void gerenciar_atuadores_aux(void){
    static uint16_t bomba_prime_timer = 0;
    if(g_ignicao_ligada && !g_motor_girando && bomba_prime_timer == 0){
        bomba_prime_timer = 2000;
    }
    
    if(g_motor_girando){
        BOMBA_COMB = 1;
        bomba_prime_timer = 0; 
    } else if(bomba_prime_timer > 0){
        BOMBA_COMB = 1;
        bomba_prime_timer--;
    } else {
        BOMBA_COMB = 0; 
    }
    
    float temperatura = (float)g_adc_temp * 0.4887f;
    
    if(temperatura > 95.0){
        RADIADOR = 1; 
    } else if (temperatura < 90.0){ 
        RADIADOR = 0;
    }
    
    if(g_modo_partida && !g_motor_girando){
        MOTOR_PARTIDA = 1;
    } else {
        MOTOR_PARTIDA = 0;
    }
    
    uint8_t erro_tps = (g_adc_tps > 1020 || g_adc_tps < 3);
    uint8_t erro_temp_alta = (temperatura > 95.0); 
    uint8_t erro_corte_giro = (g_rpm_real > RPM_LIMITE); 
    
    if (erro_tps || erro_temp_alta || erro_corte_giro) {
        LED_CHECK = 1;
    } else {
        LED_CHECK = 0; 
    }
}

/*
 * Foi necessaria implementar para converter numero inteiro de 16 bits em
 * string de caracteres por conta da memoria sprintf consumir muita memoria.
*/
void itoa(uint16_t valor, char* buffer) {
    uint8_t i = 0;
    uint16_t divisor = 10000; // maximo divisor para 16 bits
    uint8_t digito_iniciado = 0; // flag para controlar os zeros a esquerda

    if (valor == 0) { // caso especial do valor ser zero absoluto
        buffer[0] = '0';
        buffer[1] = '\0';
        return;
    }

    // loop de decomposicao decimal (milhar > centena > dezena > unidade)
    while (divisor > 0) {
        uint8_t digito = (valor / divisor) % 10; // extrai o digito mais significativo atual
        if (digito > 0 || digito_iniciado) { // so imprime se for > 0 ou algo ja ter sido imprimido antes
            buffer[i] = digito + '0';  // converte int para char com base na tabela ascii
            i++;
            digito_iniciado = 1; // marca a flag que comecaram numeros validos
        } else if (divisor == 1 && digito_iniciado == 0) { // tratamento apra o utimo digito ser zero
            buffer[i] = '0';
            i++;
        }
        divisor /= 10; // passa para a proxima casa decimal
    }
    buffer[i] = '\0'; // finaliza a string
}
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

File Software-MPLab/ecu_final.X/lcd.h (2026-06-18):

//LCD Functions Developed by electroSome
#include <xc.h>

#define RS PORTDbits.RD4 
#define EN PORTDbits.RD6 

#define D4 PORTDbits.RD0 
#define D5 PORTDbits.RD1 
#define D6 PORTDbits.RD2 
#define D7 PORTDbits.RD3 

#define TRIS_RS TRISDbits.TRISD4
#define TRIS_EN TRISDbits.TRISD6
#define TRIS_D4 TRISDbits.TRISD0
#define TRIS_D5 TRISDbits.TRISD1
#define TRIS_D6 TRISDbits.TRISD2
#define TRIS_D7 TRISDbits.TRISD3

void Lcd_Port(char a)
{
	if(a & 1)
		D4 = 1;
	else
		D4 = 0;

	if(a & 2)
		D5 = 1;
	else
		D5 = 0;

	if(a & 4)
		D6 = 1;
	else
		D6 = 0;

	if(a & 8)
		D7 = 1;
	else
		D7 = 0;
}
void Lcd_Cmd(char a)
{
	RS = 0;             // => RS = 0
	Lcd_Port(a);
	EN  = 1;             // => E = 1
        __delay_ms(10);
        EN  = 0;             // => E = 0
}

void Lcd_Clear()
{
	Lcd_Cmd(0);
	Lcd_Cmd(1);
}

void Lcd_Set_Cursor(char a, char b)
{
	char temp,z,y;
	if(a == 1)
	{
	  temp = 0x80 + b - 1;
		z = temp>>4;
		y = temp & 0x0F;
		Lcd_Cmd(z);
		Lcd_Cmd(y);
	}
	else if(a == 2)
	{
		temp = 0xC0 + b - 1;
		z = temp>>4;
		y = temp & 0x0F;
		Lcd_Cmd(z);
		Lcd_Cmd(y);
	}
}

void Lcd_Init()
{
  Lcd_Port(0x00);
   __delay_ms(20);
  Lcd_Cmd(0x03);
	__delay_ms(5);
  Lcd_Cmd(0x03);
	__delay_ms(11);
  Lcd_Cmd(0x03);
  /////////////////////////////////////////////////////
  Lcd_Cmd(0x02);
  Lcd_Cmd(0x02);
  Lcd_Cmd(0x08);
  Lcd_Cmd(0x00);
  Lcd_Cmd(0x0C);
  Lcd_Cmd(0x00);
  Lcd_Cmd(0x06);
}

void Lcd_Write_Char(char a)
{
   char temp,y;
   temp = a&0x0F;
   y = a&0xF0;
   RS = 1;             // => RS = 1
   Lcd_Port(y>>4);             //Data transfer
   EN = 1;
   __delay_us(200);
   EN = 0;
   Lcd_Port(temp);
   EN = 1;
   __delay_us(200);
   EN = 0;
}

void Lcd_Write_String(char *a)
{
	int i;
	for(i=0;a[i]!='\0';i++)
	   Lcd_Write_Char(a[i]);
}

void Lcd_Shift_Right()
{
	Lcd_Cmd(0x01);
	Lcd_Cmd(0x0C);
}

void Lcd_Shift_Left()
{
	Lcd_Cmd(0x01);
	Lcd_Cmd(0x08);
}
